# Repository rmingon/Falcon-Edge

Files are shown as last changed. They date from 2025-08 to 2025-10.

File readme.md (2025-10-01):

# FALCON-EDGE — An Open-Source Flying-Wing with an ESP32 Flight Computer

This repository contains hardware designs, documentation, and code for an aircraft project.

### New light version 400g instead of 800g

Falcon-Edge light

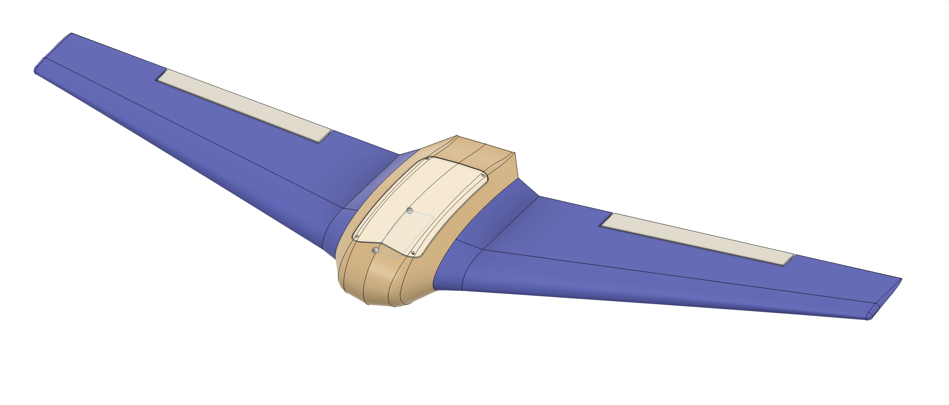
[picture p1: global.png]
Falcon-Edge render


Falcon-Edge is a compact flying-wing airframe with a custom **ESP32-based flight computer**.  
This repo contains the **KiCad hardware project** and **3D CAD** needed to print, assemble, and fly your own Falcon-Edge.

---

## Highlights

- **Airframe**

  - 3D-printable center pod with **top and bottom service hatches** for fast access.
  - Designed for clean airflow over the pod; embedded antenna keep-out zone.
  - Uses off-the-shelf wing cores/foam or your own prints.

- **Avionics (KiCad)**
  - **ESP32-WROOM** module as the main controller (Wi-Fi/BLE for ground testing & logs).
  - **IMU:** MPU-6050 6-axis.
  - **Baro:** BMP280.
  - **GNSS header** for a u-blox NEO-style GPS module.
  - **Power:** AMS1117 regulators (3V3/5V) and dedicated servo power planes/decoupling.
  - **Programming:** UART header with EN/BOOT auto-reset circuitry.
  - **RF/Telemetry:** LoRa with edge SMA/U.FL footprint for an external antenna.

> See the schematic for exact pin mapping and connector naming.

---

## 📂 Repository Layout

hardware/ # KiCad project (.kicad_pro, .kicad_pcb, .kicad_sch, etc.)
cad/ # 3D parts for the center pod, hatches, and mounting (STLs/STEP)
images/ # Renders and board views used in this README (optional)

(If you keep everything at the repo root, this README references the images there by filename.)

---

## 🛠️ Getting Started

### 1) Hardware (KiCad)

- Open with **KiCad 8.x** or newer.
- Files:
  - `hardware.kicad_pro` – project
  - `hardware.kicad_sch` – schematic
  - `hardware.kicad_pcb` – PCB layout
- Generate Gerbers/BoM as usual and order from your preferred fab.

**Board preview**
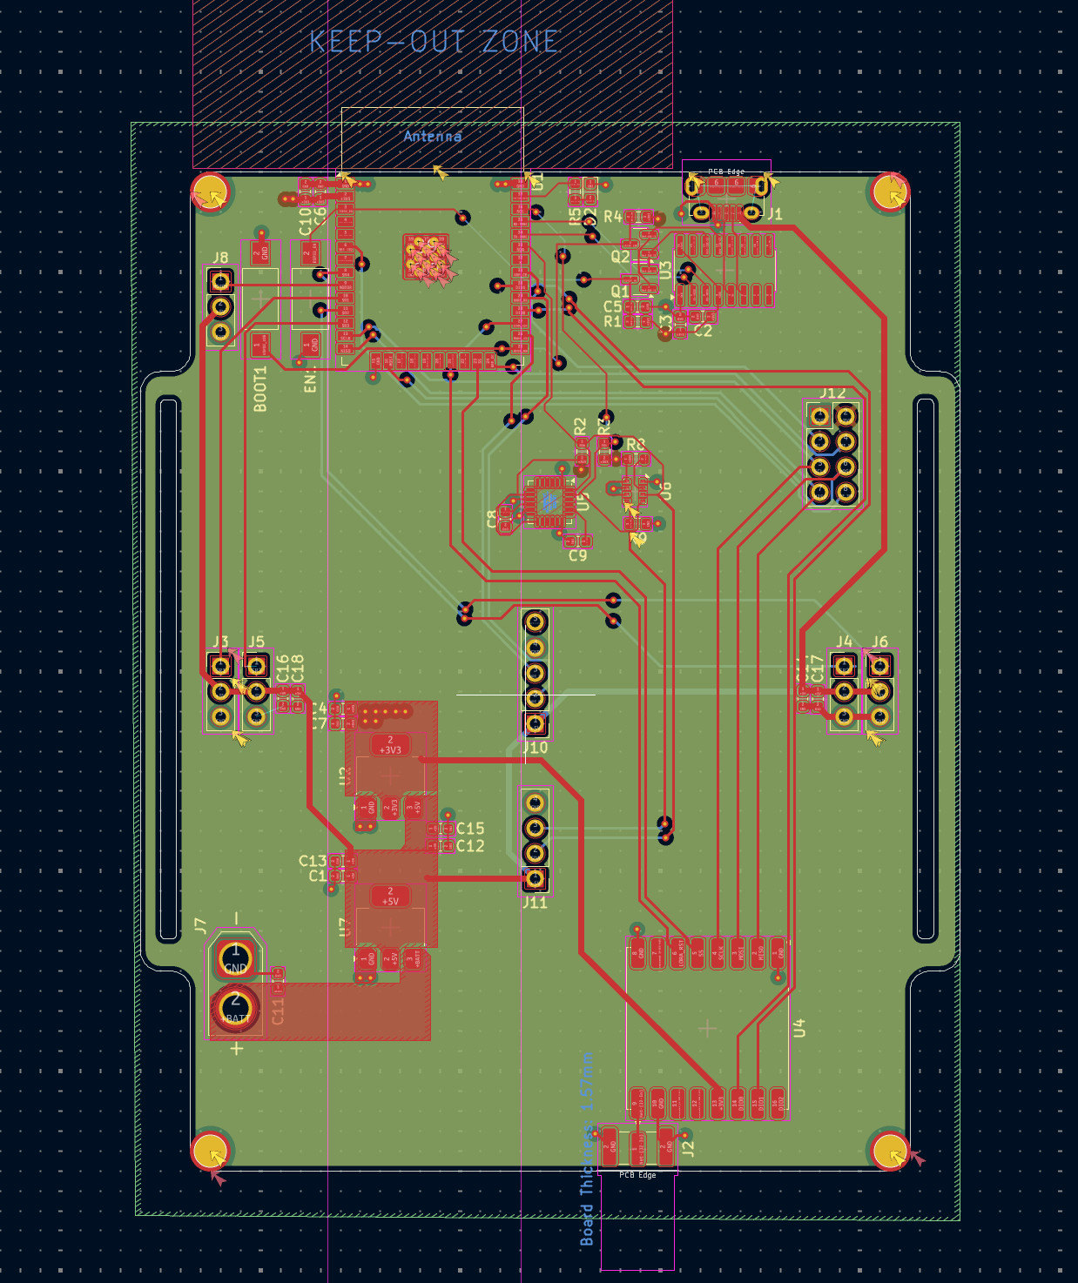
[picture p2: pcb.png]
PCB top


**Schematic overview**
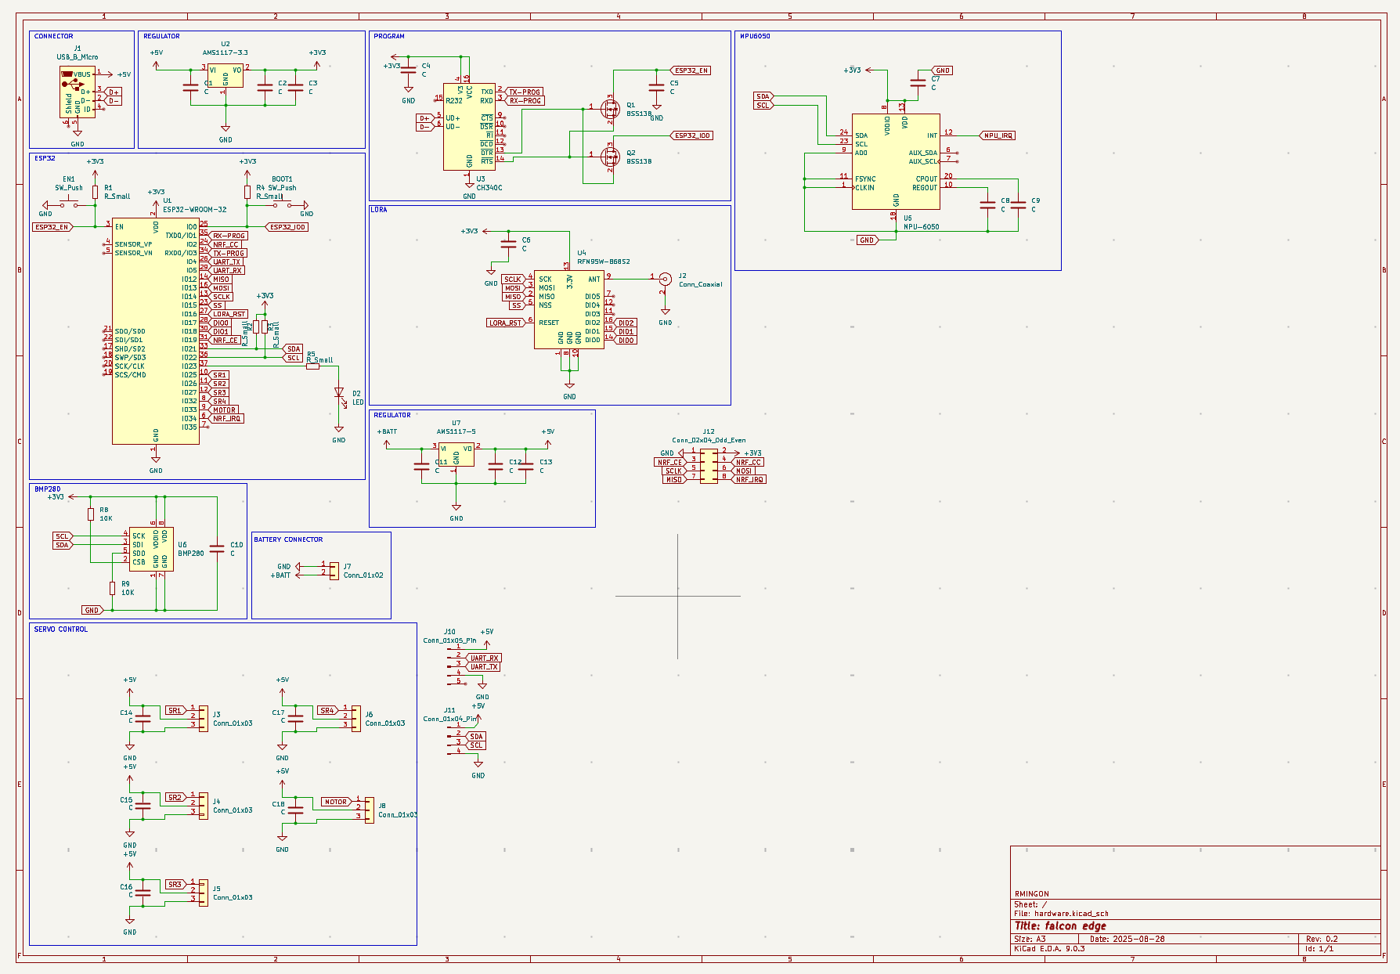
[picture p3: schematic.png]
Schematic


### 2) Print & Fit the Pod

- Recommended: **PETG** or **ABS** for the pod & hatches (heat-tolerant in the sun).
- Use heat-set **M3 inserts** for the hatch screws and board standoffs.
- Verify antenna **keep-out** in the pod before final mounting.

**Top hatch opening**
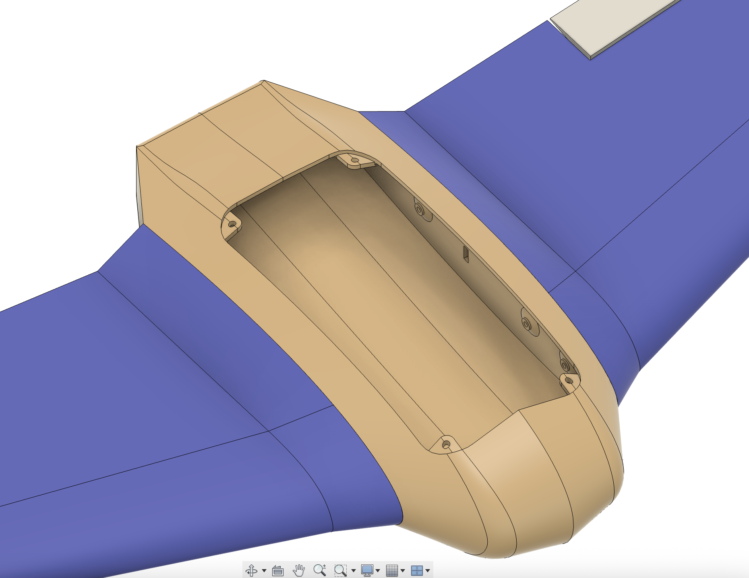
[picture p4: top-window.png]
Top hatch opening


**Bottom hatch opening**
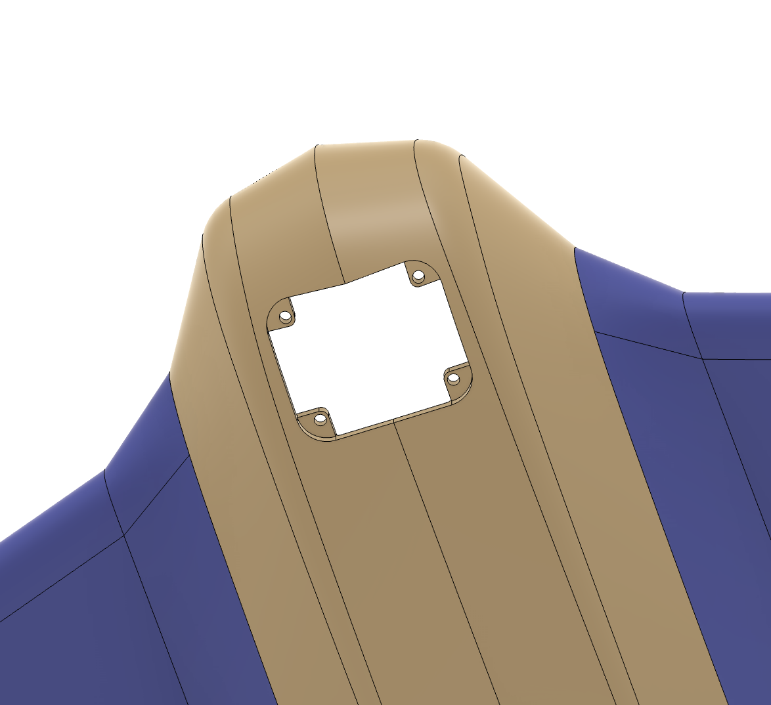
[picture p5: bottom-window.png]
Bottom hatch opening


### 3) Wiring (at a glance)

- **Battery in** → power/battery header near regulators.
- **GPS** → dedicated UART header / GPS footprint.
- **Programming** → UART (EN/BOOT accessible).
- **Telemetry/Radio** → SMA/U.FL at the board edge.

> Exact connector names/positions: see the KiCad schematic & silkscreen.

---

## 📸 Gallery

**3D view of the board**
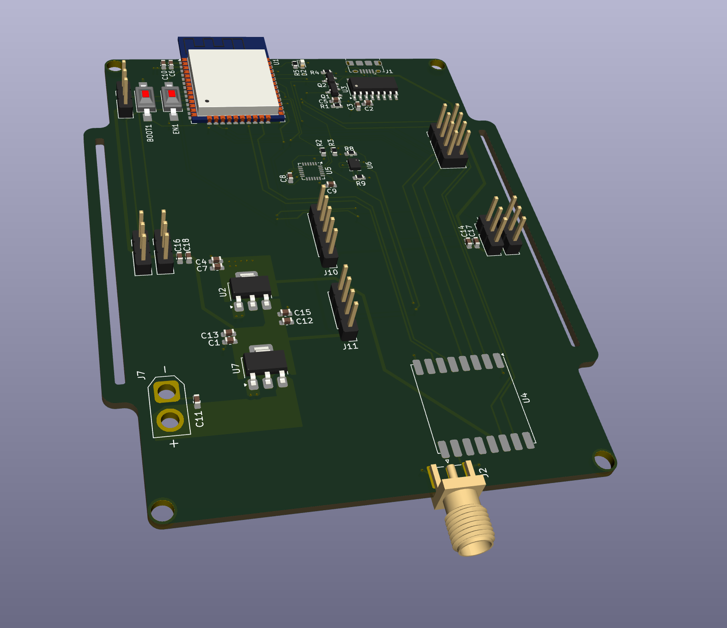
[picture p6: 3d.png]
3D board


**Airframe with pod & hatches**
Airframe render

---

## 📏 Design Notes & Decisions

- **ESP32** was chosen for its strong dev-tooling and built-in wireless (great for bench testing/logging).
- **I²C sensor stack** (MPU-6050 + BMP280) keeps routing simple and expandable.
- **PCA9685** provides plenty of PWM channels beyond the two elevons (landing gear, camera gimbal, accessories).
- **Serviceability first:** both hatches allow quick access to battery, connectors, and the main board.

---

## 🗺️ Roadmap

- Flight firmware & mixer (stabilization, RTL, waypointing).
- Airspeed/Pitot and magnetometer options.
- On-board logging (SPI flash / SD).
- CAN/Telemetry radio module footprints.
- STL release of wing cores/center pod variants.

---

## 🤝 Contributing

PRs and issues are welcome:

- Hardware changes: update the KiCad files and include board screenshots.
- CAD tweaks: include STEP/STL and a short note on print settings.
- Please attach images when reporting fit or routing problems.

---

## License Overview

- **Hardware (schematics, PCB, CAD, design files):** CERN-OHL-S-2.0 (see `LICENSE-hardware`)
- **Documentation, images, drawings, renders:** CC BY 4.0 (see `LICENSE-docs`)
- **Software / firmware / scripts:** Apache 2.0 (see `LICENSE-code`)

## Attribution Requirement

If you use, modify, or redistribute any part of this project, you **must** give credit as follows:

> Based on FalconEgde by Rmingon (https://github.com/rmingon/Falcon-Edge) — Licensed under the corresponding license.

See `NOTICE` for full details.

---

## 🙏 Credits

Designed and built by **RMINGON**.

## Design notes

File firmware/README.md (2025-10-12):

# Falcon-Edge Flight Controller Firmware

FreeRTOS-based ESP32 firmware for a drone flight controller with altitude and attitude control.

## Hardware Configuration

### ESP32 Pinout

#### I2C Bus (Sensors)
- **SDA**: GPIO 21
- **SCL**: GPIO 22

Connected sensors:
- **BMP280** - Barometric pressure/altitude sensor (I2C address: 0x76)
- **HMC5883L** - 3-axis magnetometer (I2C address: 0x1E)
- **MPU6050** - 6-axis IMU (accelerometer + gyroscope) (I2C address: 0x68)

#### SPI Bus (LoRa)
- **MISO**: GPIO 12
- **MOSI**: GPIO 13
- **SCK**: GPIO 14
- **SS/CS**: GPIO 15
- **RST**: GPIO 16
- **DIO0**: GPIO 17 (interrupt line)
- **DIO1**: GPIO 18 (interrupt line)

Connected device:
- **RFM95** - LoRa transceiver module (915 MHz)

#### UART (GPS)
- **TX**: GPIO 4
- **RX**: GPIO 5

Connected device:
- **ATGM336H** - GPS module (9600 baud, NMEA protocol)

## Features

### Sensors
- **MPU6050**: 6-axis IMU (3-axis accelerometer + 3-axis gyroscope)
- **HMC5883L**: 3-axis magnetometer for heading measurement
- **BMP280**: Barometric pressure sensor for altitude measurement
- **ATGM336H**: GPS module for position tracking

### Control System
- **PID Controllers**:
  - Altitude control (using BMP280 barometer)
  - Roll control (using IMU data)
  - Pitch control (using IMU data)
  - Yaw control (using magnetometer + gyro)

- **Sensor Fusion**:
  - Complementary filter for roll/pitch (combines accelerometer and gyroscope)
  - Magnetometer-based yaw with tilt compensation
  - Gyroscope integration with magnetometer correction

### Communication
- **LoRa telemetry**: Sends real-time flight data (attitude, altitude, GPS position)
- **Command reception**: Receives commands via LoRa (arm, disarm, set setpoints)

### FreeRTOS Tasks
1. **Sensor Task** (100 Hz) - Reads all sensors
2. **Control Task** (100 Hz) - Updates attitude estimation and PID controllers
3. **GPS Task** (10 Hz) - Processes GPS data
4. **LoRa Task** (1 Hz) - Sends telemetry
5. **Command Task** - Receives and processes LoRa commands

## Building and Flashing

### Prerequisites
- ESP-IDF v4.4 or later
- PlatformIO (optional)

### Using PlatformIO
```bash
cd firmware
pio run -t upload
pio device monitor
```

### Using ESP-IDF
```bash
cd firmware
idf.py build
idf.py -p /dev/ttyUSB0 flash monitor
```

## Configuration

All configuration parameters are in [include/config.h](include/config.h):

- **Sensor pins and I2C settings**
- **LoRa frequency and SPI pins**
- **GPS UART settings**
- **PID tuning parameters** (Kp, Ki, Kd)
- **Task priorities and stack sizes**
- **Sensor sample rates**

### PID Tuning

Default PID parameters are set in [config.h](include/config.h). You can tune them for your specific setup:

```c
// Altitude PID
#define ALT_PID_KP    2.0f
#define ALT_PID_KI    0.5f
#define ALT_PID_KD    1.0f

// Roll PID
#define ROLL_PID_KP   1.5f
#define ROLL_PID_KI   0.3f
#define ROLL_PID_KD   0.8f

// Pitch PID
#define PITCH_PID_KP  1.5f
#define PITCH_PID_KI  0.3f
#define PITCH_PID_KD  0.8f

// Yaw PID
#define YAW_PID_KP    2.0f
#define YAW_PID_KI    0.1f
#define YAW_PID_KD    1.2f
```

## LoRa Commands

The system accepts the following commands via LoRa:

### Arm Command
Send single byte: `'A'` (0x41)
- Arms the flight controller and enables control outputs

### Disarm Command
Send single byte: `'D'` (0x44)
- Disarms the flight controller and zeros all outputs

### Set Setpoints Command
Send 17 bytes: `'S'` + 4 floats (altitude, roll, pitch, yaw)
- Format: `['S'][altitude][roll][pitch][yaw]`
- Each float is 4 bytes (little-endian)
- Example: Set altitude to 10m, level attitude (0° roll/pitch), 90° heading

## Telemetry Data

Telemetry is sent via LoRa every second containing:
- Roll (degrees)
- Pitch (degrees)
- Yaw (degrees)
- Altitude (meters)
- GPS latitude (degrees)
- GPS longitude (degrees)
- Number of GPS satellites
- Armed status (1 byte boolean)

Total packet size: ~30 bytes

## System Architecture

```
┌─────────────────────────────────────────────────────┐
│                    ESP32 Main                        │
│  ┌────────────────────────────────────────────────┐ │
│  │         FreeRTOS Task Scheduler                │ │
│  └────────────────────────────────────────────────┘ │
│                                                       │
│  ┌──────────┐  ┌───────────┐  ┌─────────┐          │
│  │  Sensor  │  │  Control  │  │  LoRa   │          │
│  │   Task   │→│   Task    │→│  Task   │          │
│  │ (100 Hz) │  │ (100 Hz)  │  │ (1 Hz)  │          │
│  └──────────┘  └───────────┘  └─────────┘          │
│       ↓              ↓                                │
│  ┌──────────────────────────────────────────────┐   │
│  │         Flight Controller Module             │   │
│  │  • Sensor Fusion (Complementary Filter)     │   │
│  │  • 4x PID Controllers                       │   │
│  │  • Attitude Estimation                      │   │
│  └──────────────────────────────────────────────┘   │
│       ↓                                               │
│  ┌──────────┬──────────┬──────────┐                 │
│  │  MPU6050 │ HMC5883L │  BMP280  │  (I2C)         │
│  └──────────┴──────────┴──────────┘                 │
│  ┌──────────┐  ┌─────────────┐                      │
│  │ ATGM336  │  │   RFM95     │                      │
│  │   GPS    │  │   LoRa      │                      │
│  └──────────┘  └─────────────┘                      │
│    (UART)          (SPI)                             │
└─────────────────────────────────────────────────────┘
```

## Safety Features

- **Calibration check**: System must be calibrated before arming
- **Armed state**: Control outputs are zero when disarmed
- **Mutex protection**: Thread-safe access to shared data
- **PID anti-windup**: Prevents integral term from growing unbounded
- **Output limiting**: All PID outputs are clamped to safe ranges

## Serial Monitor Output

When running, you'll see output like:
```
I (1234) Main: Attitude: R=2.3° P=-1.5° Y=45.2° | Alt=123.45m | GPS: 37.774929,-122.419418 (8 sats)
I (1234) Main: Control outputs: Alt=15.2 Roll=-3.4 Pitch=2.1 Yaw=0.8
```

## License

See the LICENSE file in the repository root.

## Troubleshooting

### Sensor initialization fails
- Check I2C connections and pull-up resistors
- Verify sensor I2C addresses (some modules use alternate addresses)
- Check power supply (3.3V for all sensors)

### GPS not getting fix
- Ensure antenna has clear view of sky
- GPS may take several minutes for first fix
- Check UART baud rate (9600 for ATGM336)

### LoRa not working
- Verify antenna is connected
- Check SPI connections
- Ensure frequency matches your region (915 MHz US, 868 MHz EU, 433 MHz Asia)
- Check DIO0/DIO1 interrupt pins are connected

### Attitude estimation drifts
- Recalibrate IMU (keep device stationary during calibration)
- Adjust complementary filter alpha values
- Check for magnetic interference affecting magnetometer

## Future Improvements

- [ ] Kalman filter for better sensor fusion
- [ ] Motor/ESC control outputs
- [ ] Battery voltage monitoring
- [ ] Failsafe modes
- [ ] SD card logging
- [ ] Web interface for configuration
- [ ] OTA firmware updates

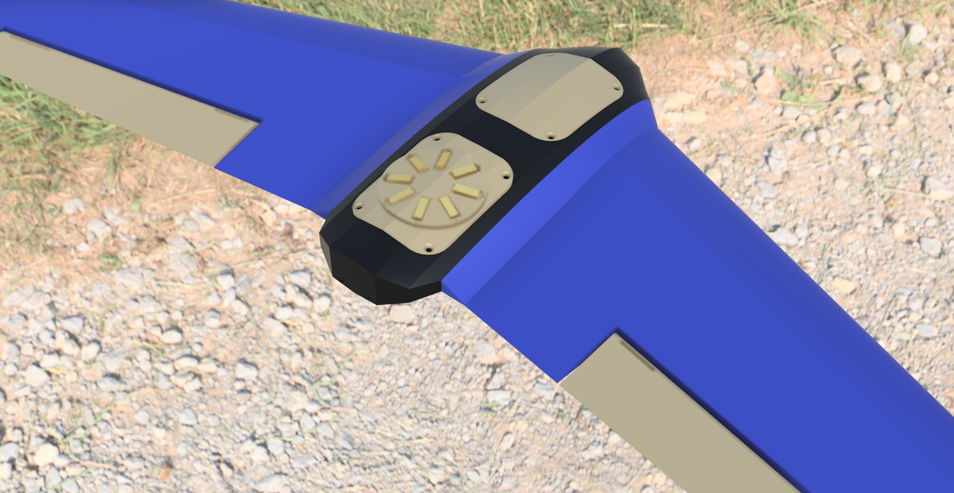
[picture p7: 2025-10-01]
plane_gps_module.png

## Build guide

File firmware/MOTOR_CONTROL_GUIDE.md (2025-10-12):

# Motor & Servo Control Guide

## Hardware Configuration

Your fixed-wing drone now has full motor and servo control!

### Pin Assignments

| Component | GPIO | Signal Type |
|---|---|---|
| **Left Wing Servo** | GPIO 26 | PWM (50Hz) |
| **Right Wing Servo** | GPIO 25 | PWM (50Hz) |
| **ESC (Motor)** | GPIO 33 | PWM (50Hz) |

### PWM Signal Specs

- **Frequency**: 50 Hz (20ms period)
- **Servo Range**: 1000-2000μs (±45° from center)
- **Servo Center**: 1500μs (neutral position)
- **ESC Range**: 1000-2000μs (0-100% throttle)
- **ESC Idle**: 1100μs (motor spinning, low throttle)

## Control Mixing (Fixed-Wing)

Your firmware implements **fixed-wing control mixing** that converts PID outputs to servo/motor commands:

### Roll Control (Ailerons)
```
Left Servo Angle  = +Roll_Output * 0.3
Right Servo Angle = -Roll_Output * 0.3
```
- Roll right (+): Left servo up, right servo down
- Roll left (-): Left servo down, right servo up

### Pitch Control (Elevators)
```
Both Servos = +Pitch_Output * 0.3
```
- Pitch up (+): Both servos up
- Pitch down (-): Both servos down

### Yaw Control (Rudder via Differential)
```
Left Servo  += +Yaw_Output * 0.1
Right Servo += -Yaw_Output * 0.1
```
- Small differential aileron for yaw stability

### Altitude Control (Throttle)
```
Throttle = 50% + Altitude_Output * 0.5
```
- Base throttle: 50%
- Adjusts ±50% based on altitude PID

## Safety Features

### Arming Sequence
1. System checks calibration
2. **ESC arming**: 2-second low throttle signal
3. PIDs reset to zero
4. Flight controller armed
5. Control outputs active

### Disarming
- All servos return to center (0°)
- Throttle set to 0%
- Control loop stops updating outputs

### Fail-Safe
When disarmed:
- Servos: Centered
- Motor: Zero throttle
- No PID updates

## Testing

### Bench Testing (NO PROPELLER!)

**Test servos:**
```c
// In your code or via serial commands
motor_set_servo_left(&motor, 20.0f);   // 20° up
motor_set_servo_right(&motor, -10.0f); // 10° down
```

**Test ESC (REMOVE PROPELLER FIRST!):**
```c
motor_set_throttle(&motor, 10.0f);  // 10% throttle - should spin slowly
```

### Serial Monitor Output

When arming:
```
I (12345) MotorControl: Motor control initialized - Left:26 Right:25 ESC:33
I (23456) FlightController: Arming flight controller
I (23457) MotorControl: Arming ESC sequence...
I (25457) MotorControl: ESC armed
I (25458) FlightController: Flight controller armed - ready to fly
```

## Tuning

### Servo Travel Adjustment

In [motor_control.c](src/motor_control.c:17):
```c
// Increase for more servo throw
float pulse = SERVO_CENTER_PULSE_US + (angle / 45.0f) * 500.0f;
                                                    // ^^^^ change this
```

### Control Surface Gains

In [flight_controller.c](src/flight_controller.c:216-226):
```c
// Aileron gain (roll)
left_servo += fc->roll_output * 0.3f;   // Increase for more roll authority

// Elevator gain (pitch)
left_servo += fc->pitch_output * 0.3f;  // Increase for more pitch authority

// Rudder gain (yaw)
left_servo += fc->yaw_output * 0.1f;    // Increase for more yaw authority
```

### Throttle Control

```c
float throttle = 50.0f;  // Base throttle (cruise speed)
throttle += fc->altitude_output * 0.5f;  // Altitude response gain
```

## Servo Reversing

If a servo moves in the wrong direction, reverse it in the mixing:

### Reverse Left Servo
```c
left_servo -= fc->roll_output * 0.3f;  // Changed + to -
```

### Reverse Right Servo
```c
right_servo += fc->roll_output * 0.3f;  // Changed - to +
```

## ESC Calibration

Some ESCs need calibration. If your ESC doesn't work:

1. **Power off** drone
2. Set throttle to **max** in code temporarily:
   ```c
   motor_set_throttle(&motor, 100.0f);
   ```
3. **Power on** drone with battery
4. Wait for ESC beeps (confirms max throttle)
5. Set throttle to **min**:
   ```c
   motor_set_throttle(&motor, 0.0f);
   ```
6. Wait for ESC beeps (confirms min throttle)
7. **Remove** temporary code, upload normal firmware

## Common Issues

### Servos jittering
- Check power supply (servos draw current)
- Add capacitor (100-470μF) to servo power rail
- Ensure common ground between ESP32 and servo power

### ESC not responding
- Check ESC is receiving 5V/3.3V signal (not vice versa)
- Verify PWM signal with oscilloscope
- Try ESC calibration procedure above
- Some ESCs need 3.3V → 5V level shifter

### Servos moving wrong direction
- See "Servo Reversing" section above
- Or swap servo connections physically

### ESC beeping continuously
- Usually means low voltage or no signal
- Check battery voltage
- Verify PWM signal present on GPIO 33

## API Reference

### Set Individual Outputs
```c
motor_set_servo_left(&motor, angle);   // -45 to +45 degrees
motor_set_servo_right(&motor, angle);  // -45 to +45 degrees
motor_set_throttle(&motor, percent);   // 0 to 100%
```

### Set All Outputs
```c
motor_set_all(&motor, left_angle, right_angle, throttle);
```

### Safety Functions
```c
motor_arm_esc(&motor);    // Run ESC arming sequence
motor_disarm(&motor);     // Stop all outputs
```

## Wiring Diagram

```
ESP32                     Servos/ESC
┌─────────┐
│ GPIO 26 ├──────────┬───► Left Wing Servo (Signal)
│         │          │
│ GPIO 25 ├──────────┼───► Right Wing Servo (Signal)
│         │          │
│ GPIO 33 ├──────────┼───► ESC (Signal)
│         │          │
│    GND  ├──────────┴───► Common Ground
└─────────┘

Power:
- Servos: 5V from BEC/ESC
- ESC: Main battery (LiPo)
- ESP32: 5V from USB or BEC (via voltage regulator)

⚠️ IMPORTANT: Common ground required!
```

## Next Steps

1. **Bench test** servos without propeller
2. **Calibrate ESC** if needed
3. **Tune mixing gains** for your aircraft
4. **Test on ground** with prop, full arm sequence
5. **Flight test** in stable conditions

Happy flying! 🚀

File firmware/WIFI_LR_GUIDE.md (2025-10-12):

# WiFi Long Range Guide

## Overview

Your ESP32 firmware now supports **WiFi Long Range (LR) mode** alongside LoRa for redundant telemetry and configuration.

## Features Added

### 1. **WiFi Long Range Mode**
- Range: Up to **1 km** line-of-sight
- Frequency: 5 Hz telemetry updates
- Dual-band support with LoRa as backup

### 2. **UDP Telemetry**
- Sends flight data to ground station at `192.168.4.1:5000`
- Same packet format as LoRa telemetry
- Lower latency than LoRa

### 3. **Remote WiFi Configuration**
- Configure WiFi via LoRa commands
- No need to reflash firmware to change networks

## Configuration

### In [config.h](include/config.h)

```c
#define WIFI_ENABLED              true        // Enable/disable WiFi
#define WIFI_DEFAULT_SSID         "DroneGCS"  // Your WiFi network
#define WIFI_DEFAULT_PASSWORD     "drone123"  // Your WiFi password
```

### Ground Station IP

Change in [wifi_lr.c](src/wifi_lr.c:10):
```c
#define GROUND_STATION_IP       "192.168.4.1"  // Your ground station IP
```

## Usage

### Auto-Connect on Startup

If you set `WIFI_DEFAULT_SSID` and `WIFI_DEFAULT_PASSWORD` in config.h, the drone will automatically connect on boot.

### Connect via LoRa Command

Send command `'W'` via LoRa with this format:
```
Byte 0: 'W' (0x57)
Byte 1: SSID length (N)
Bytes 2 to N+1: SSID string
Bytes N+2 to end: Password string
```

**Example Python code to send WiFi config:**
```python
import struct

ssid = "MyDrone"
password = "password123"

packet = bytearray()
packet.append(ord('W'))           # Command
packet.append(len(ssid))          # SSID length
packet.extend(ssid.encode())      # SSID
packet.extend(password.encode())  # Password

# Send packet via your LoRa module
lora.send(packet)
```

## Ground Station Setup

### Simple UDP Receiver (Python)

```python
import socket
import struct

UDP_IP = "0.0.0.0"
UDP_PORT = 5000

sock = socket.socket(socket.AF_INET, socket.SOCK_DGRAM)
sock.bind((UDP_IP, UDP_PORT))

print(f"Listening for telemetry on {UDP_IP}:{UDP_PORT}")

while True:
    data, addr = sock.recvfrom(1024)

    if len(data) >= 29:
        # Unpack telemetry
        roll, pitch, yaw, alt, lat, lon, sats, armed = struct.unpack('<ffffffBB', data[:29])

        print(f"Drone at {addr[0]}:")
        print(f"  Attitude: R={roll:.1f}° P={pitch:.1f}° Y={yaw:.1f}°")
        print(f"  Altitude: {alt:.2f}m")
        print(f"  GPS: {lat:.6f}, {lon:.6f} ({sats} sats)")
        print(f"  Armed: {bool(armed)}")
        print()
```

## Serial Monitor Output

When WiFi is working, you'll see:
```
I (12345) WiFi_LR: WiFi Long Range mode initialized
I (12456) WiFi_LR: Connecting to WiFi: DroneGCS
I (15234) WiFi_LR: Got IP: 192.168.4.2
I (15345) Main: WiFi task started
I (20000) Main: WiFi connected, RSSI: -45 dBm
```

## Troubleshooting

### WiFi won't connect
1. Check SSID and password in config.h
2. Ensure AP supports 802.11n or 802.11b/g
3. Check serial monitor for error messages
4. Verify ESP32 is in range (~1km max)

### No telemetry received
1. Check ground station IP in wifi_lr.c
2. Verify UDP port 5000 is not blocked by firewall
3. Ensure ground station is on same network
4. Check RSSI in serial monitor (should be > -80 dBm)

### High packet loss
- Move closer to AP (check RSSI)
- Reduce obstacles between drone and AP
- Lower `WIFI_TX_RATE_HZ` in config.h to reduce bandwidth

## Disable WiFi

To disable WiFi completely:

In [config.h](include/config.h):
```c
#define WIFI_ENABLED    false
```

This will remove WiFi task and save memory.

## Comparison: WiFi LR vs LoRa

| Feature | WiFi LR | LoRa |
|---|---|---|
| **Range** | ~1 km | 2-15 km |
| **Data Rate** | 5 Hz | 1 Hz |
| **Latency** | ~10 ms | ~100 ms |
| **Power** | Higher | Lower |
| **Best For** | Near-field ops | Long-range |

**Recommendation**: Use both! WiFi for low-latency control near base, LoRa for long-range missions.

## Advanced: Bidirectional Commands via WiFi

You can easily extend the WiFi module to receive commands (not just send telemetry):

1. Add TCP server in wifi_lr.c
2. Parse incoming command packets
3. Call flight controller functions

This would allow real-time parameter tuning over WiFi!

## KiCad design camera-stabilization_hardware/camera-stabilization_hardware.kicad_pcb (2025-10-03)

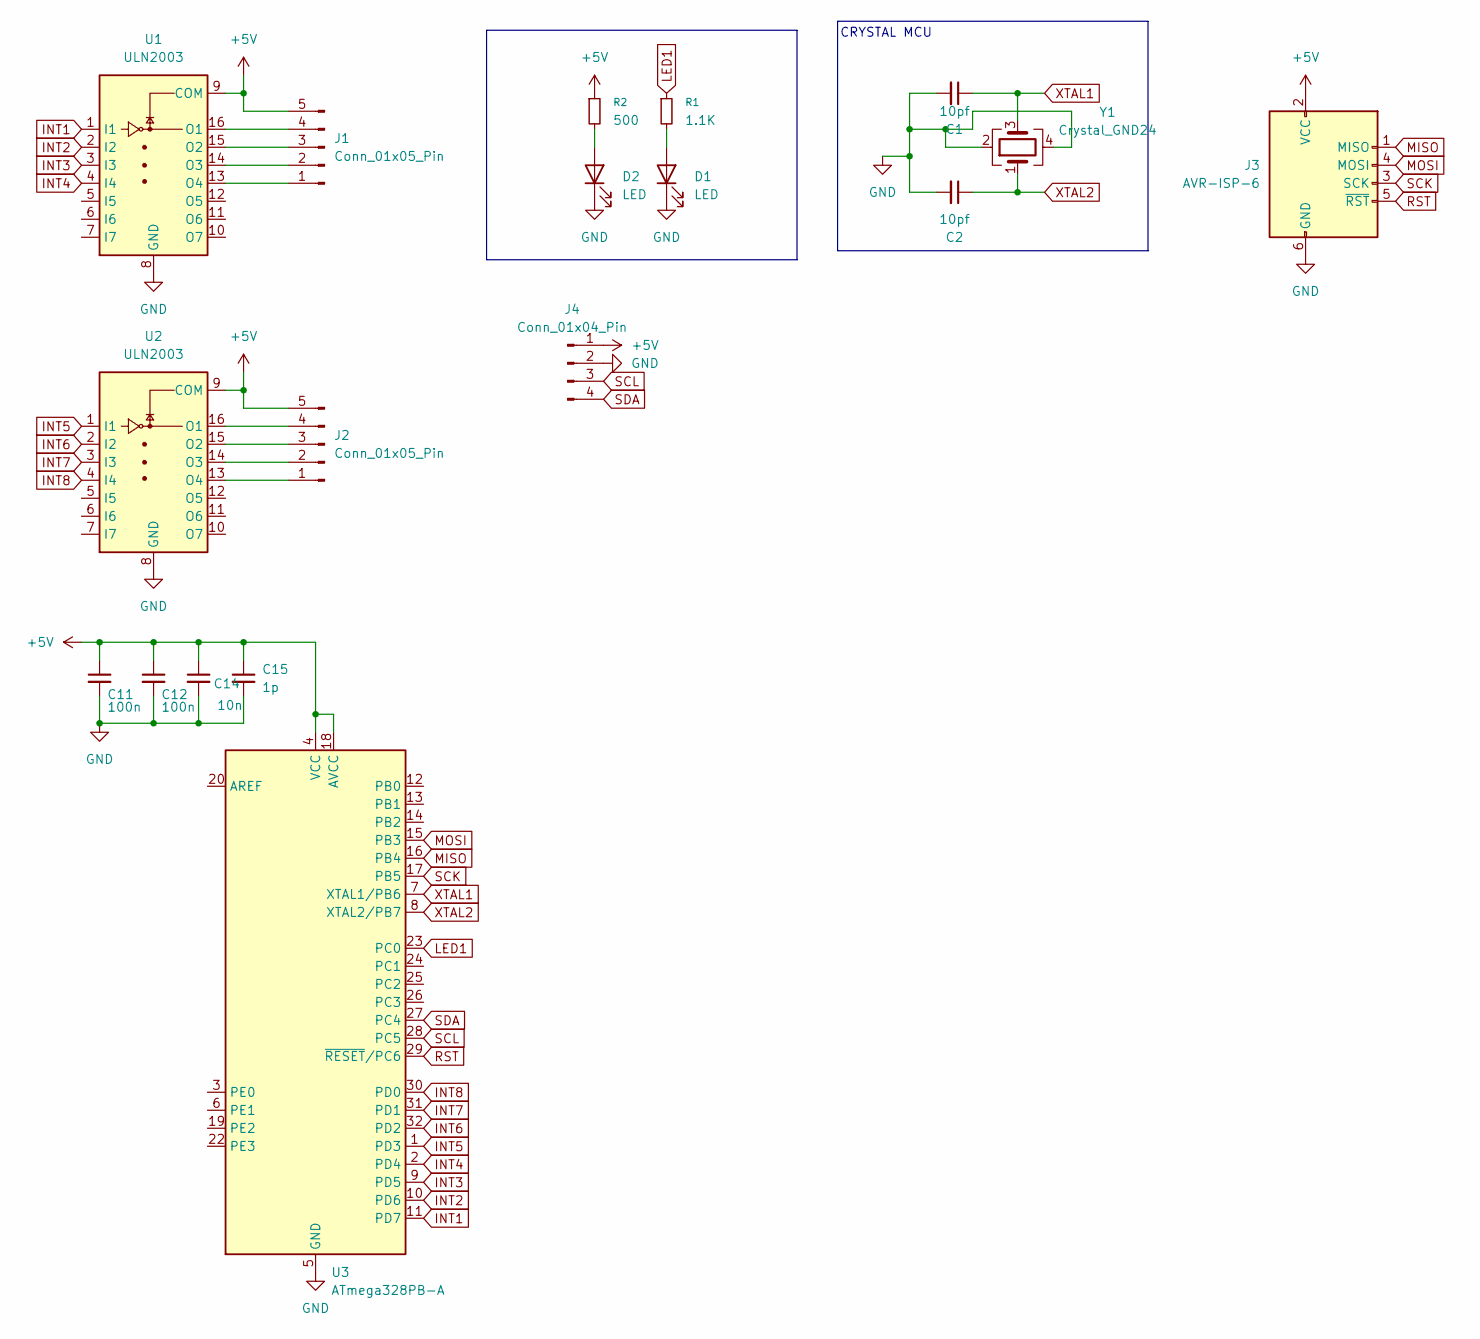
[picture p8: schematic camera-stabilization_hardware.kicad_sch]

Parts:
C1, C2: 10pf; C_0603_1608Metric; LCSC C106245
C11, C12: 100n; C_0603_1608Metric
C14: 10n; C_0603_1608Metric
C15: 1p; C_0603_1608Metric
D1, D2: LED; LED_0603_1608Metric
J1, J2: Conn_01x05_Pin; JST_XH_B5B-XH-A_1x05_P2.50mm_Vertical
J3: AVR-ISP-6; PinHeader_2x03_P2.54mm_Vertical
J4: Conn_01x04_Pin; JST_SH_BM04B-SRSS-TB_1x04-1MP_P1.00mm_Vertical
R1: 1.1K; R_0603_1608Metric
R2: 500; R_0603_1608Metric
U1, U2: ULN2003; SOIC-16_3.9x9.9mm_P1.27mm
U3: ATmega328PB-A; TQFP-32_7x7mm_P0.8mm
Y1: Crystal_GND24; Crystal_SMD_3225-4Pin_3.2x2.5mm

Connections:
+5V: C11.1, C12.1, C14.1, C15.1, J1.5, J2.5, J3.2 (VCC), J4.1, R2.1, U1.9 (COM), U2.9 (COM), U3.4 (VCC), U3.18 (AVCC)
GND: C1.2, C2.2, C11.2, C12.2, C14.2, C15.2, D1.1 (K), D2.1 (K), J3.6 (GND), J4.2, U1.8 (GND), U2.8 (GND), U3.5 (GND), U3.21 (GND), Y1.2, Y1.4
INT1: U1.1 (I1), U3.11 (PD7)
INT2: U1.2 (I2), U3.10 (PD6)
INT3: U1.3 (I3), U3.9 (PD5)
INT4: U1.4 (I4), U3.2 (PD4)
INT5: U2.1 (I1), U3.1 (PD3)
INT6: U2.2 (I2), U3.32 (PD2)
INT7: U2.3 (I3), U3.31 (PD1)
INT8: U2.4 (I4), U3.30 (PD0)
LED1: R1.1, U3.23 (PC0)
MISO: J3.1 (MISO), U3.16 (PB4)
MOSI: J3.4 (MOSI), U3.15 (PB3)
unnamed: D1.2 (A), R1.2
unnamed: D2.2 (A), R2.2
unnamed: J1.1, U1.13 (O4)
unnamed: J1.2, U1.14 (O3)
unnamed: J1.3, U1.15 (O2)
unnamed: J1.4, U1.16 (O1)
unnamed: J2.1, U2.13 (O4)
unnamed: J2.2, U2.14 (O3)
unnamed: J2.3, U2.15 (O2)
unnamed: J2.4, U2.16 (O1)
RST: J3.5 (~RST), U3.29 (~RESET/PC6)
SCK: J3.3 (SCK), U3.17 (PB5)
SCL: J4.3, U3.28 (PC5)
SDA: J4.4, U3.27 (PC4)
XTAL1: C1.1, U3.7 (XTAL1/PB6), Y1.3
XTAL2: C2.1, U3.8 (XTAL2/PB7), Y1.1

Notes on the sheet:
CRYSTAL MCU

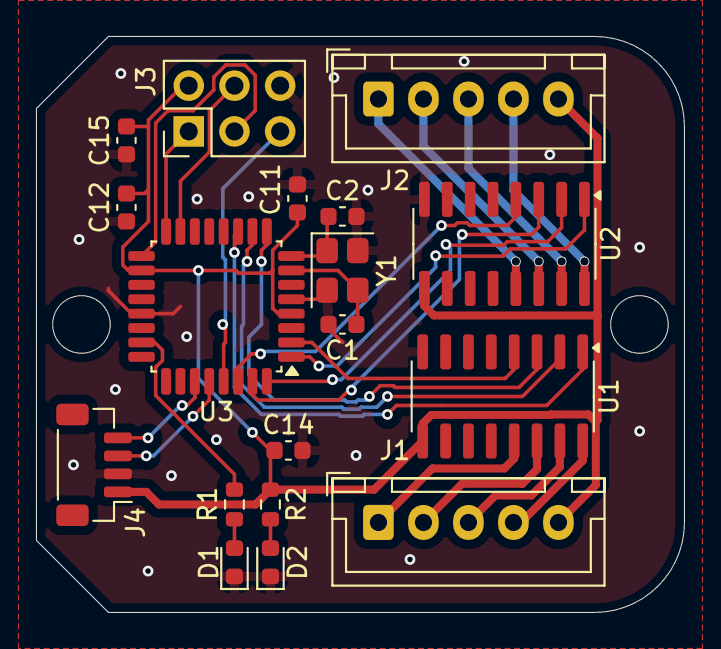
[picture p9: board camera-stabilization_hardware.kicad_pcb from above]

Board: 2 copper layers, 36.0 x 32.0 mm, 18 parts (0 on the bottom side), 29 nets.

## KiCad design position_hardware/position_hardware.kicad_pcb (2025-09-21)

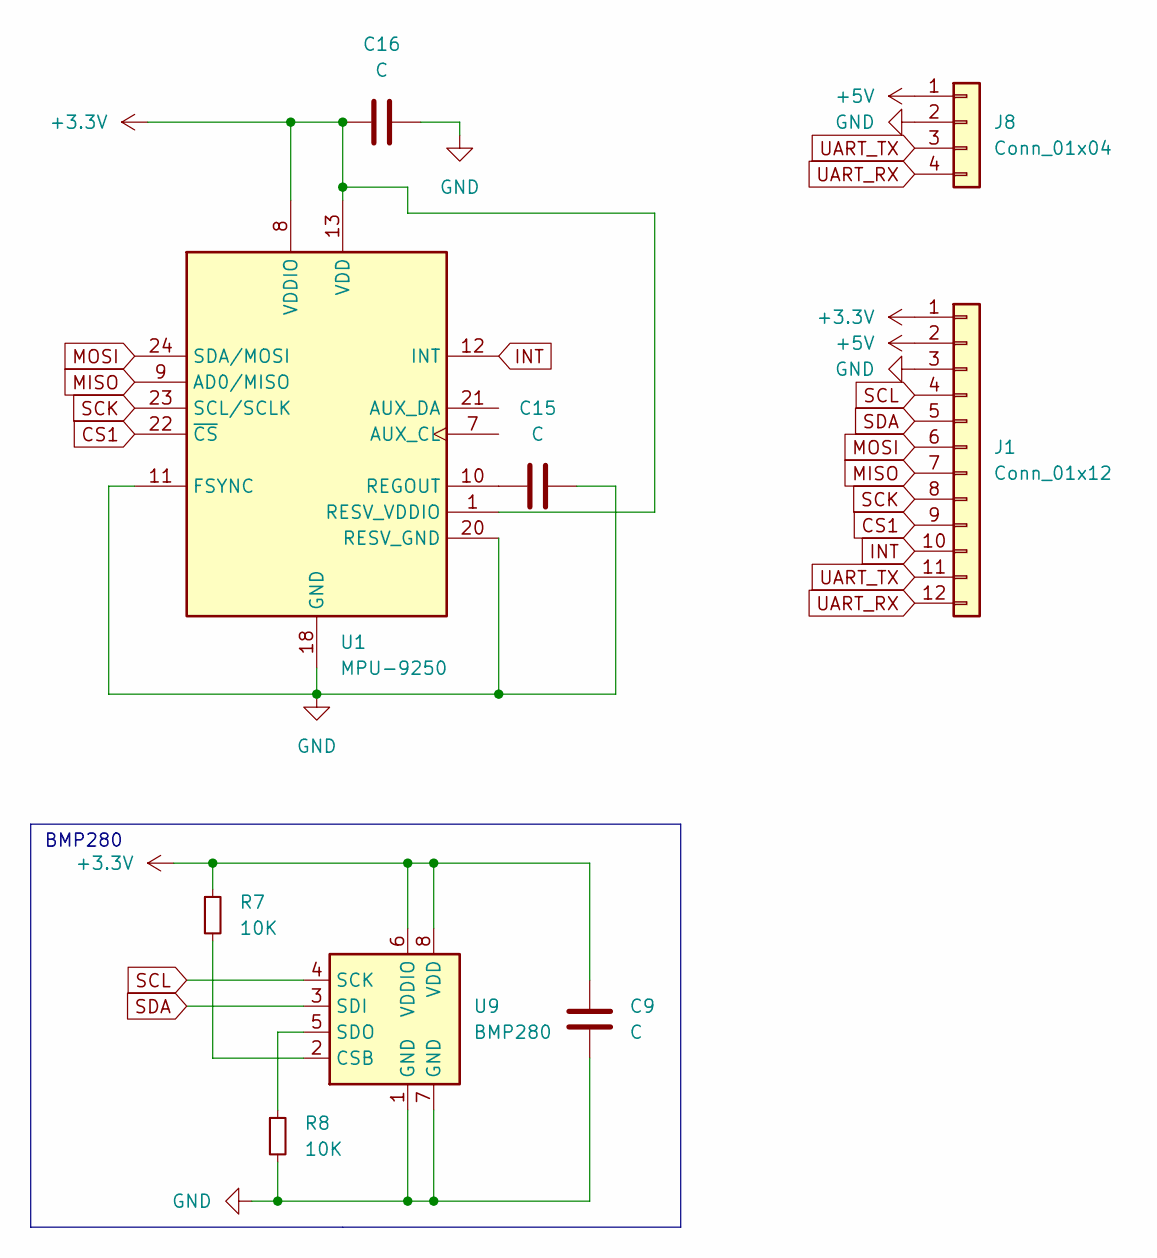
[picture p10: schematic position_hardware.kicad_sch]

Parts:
C9, C15, C16: C; C_0603_1608Metric
J1: Conn_01x12
J8: Conn_01x04; PinHeader_1x04_P2.54mm_Vertical
R7, R8: 10K; R_0603_1608Metric
U1: MPU-9250; InvenSense_QFN-24_3x3mm_P0.4mm
U9: BMP280; Bosch_LGA-8_2x2.5mm_P0.65mm_ClockwisePinNumbering

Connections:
+3.3V: C9.1, C16.1, J1.1, R7.1, U1.1 (RESV_VDDIO), U1.8 (VDDIO), U1.13 (VDD), U9.6 (VDDIO), U9.8 (VDD)
+5V: J1.2, J8.1
CS1: J1.9, U1.22 (~CS)
GND: C9.2, C15.2, C16.2, J1.3, J8.2, R8.2, U1.11 (FSYNC), U1.18 (GND), U1.20 (RESV_GND), U9.1 (GND), U9.7 (GND)
INT: J1.10, U1.12 (INT)
MISO: J1.7, U1.9 (AD0/MISO)
MOSI: J1.6, U1.24 (SDA/MOSI)
unnamed: C15.1, U1.10 (REGOUT)
unnamed: R7.2, U9.2 (CSB)
unnamed: R8.1, U9.5 (SDO)
SCK: J1.8, U1.23 (SCL/SCLK)
SCL: J1.4, U9.4 (SCK)
SDA: J1.5, U9.3 (SDI)
UART_RX: J1.12, J8.4
UART_TX: J1.11, J8.3

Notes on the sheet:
BMP280

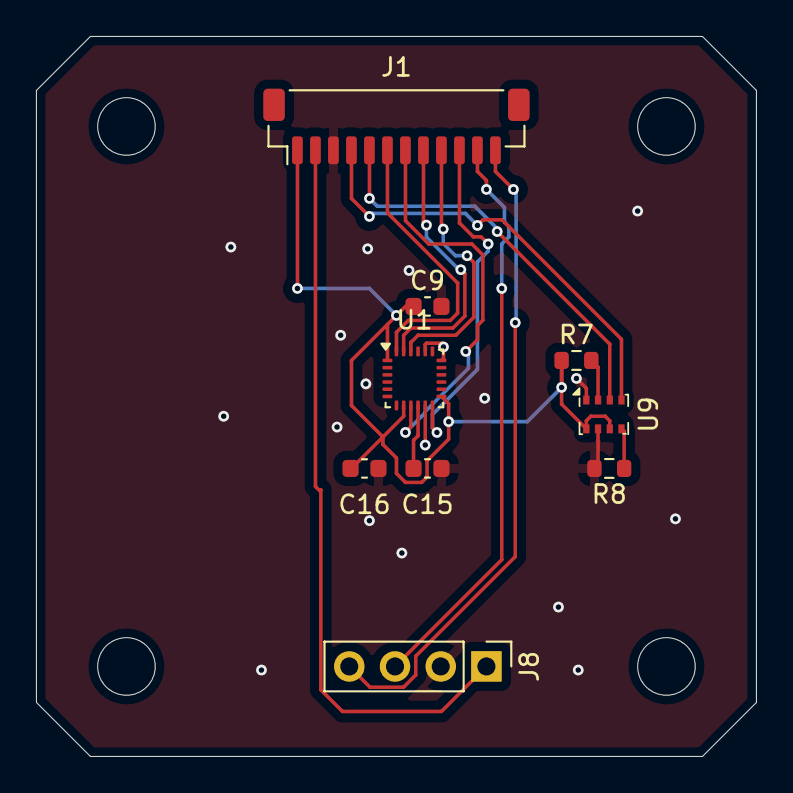
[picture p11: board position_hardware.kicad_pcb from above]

Board: 2 copper layers, 40.0 x 40.0 mm, 9 parts (0 on the bottom side), 15 nets.

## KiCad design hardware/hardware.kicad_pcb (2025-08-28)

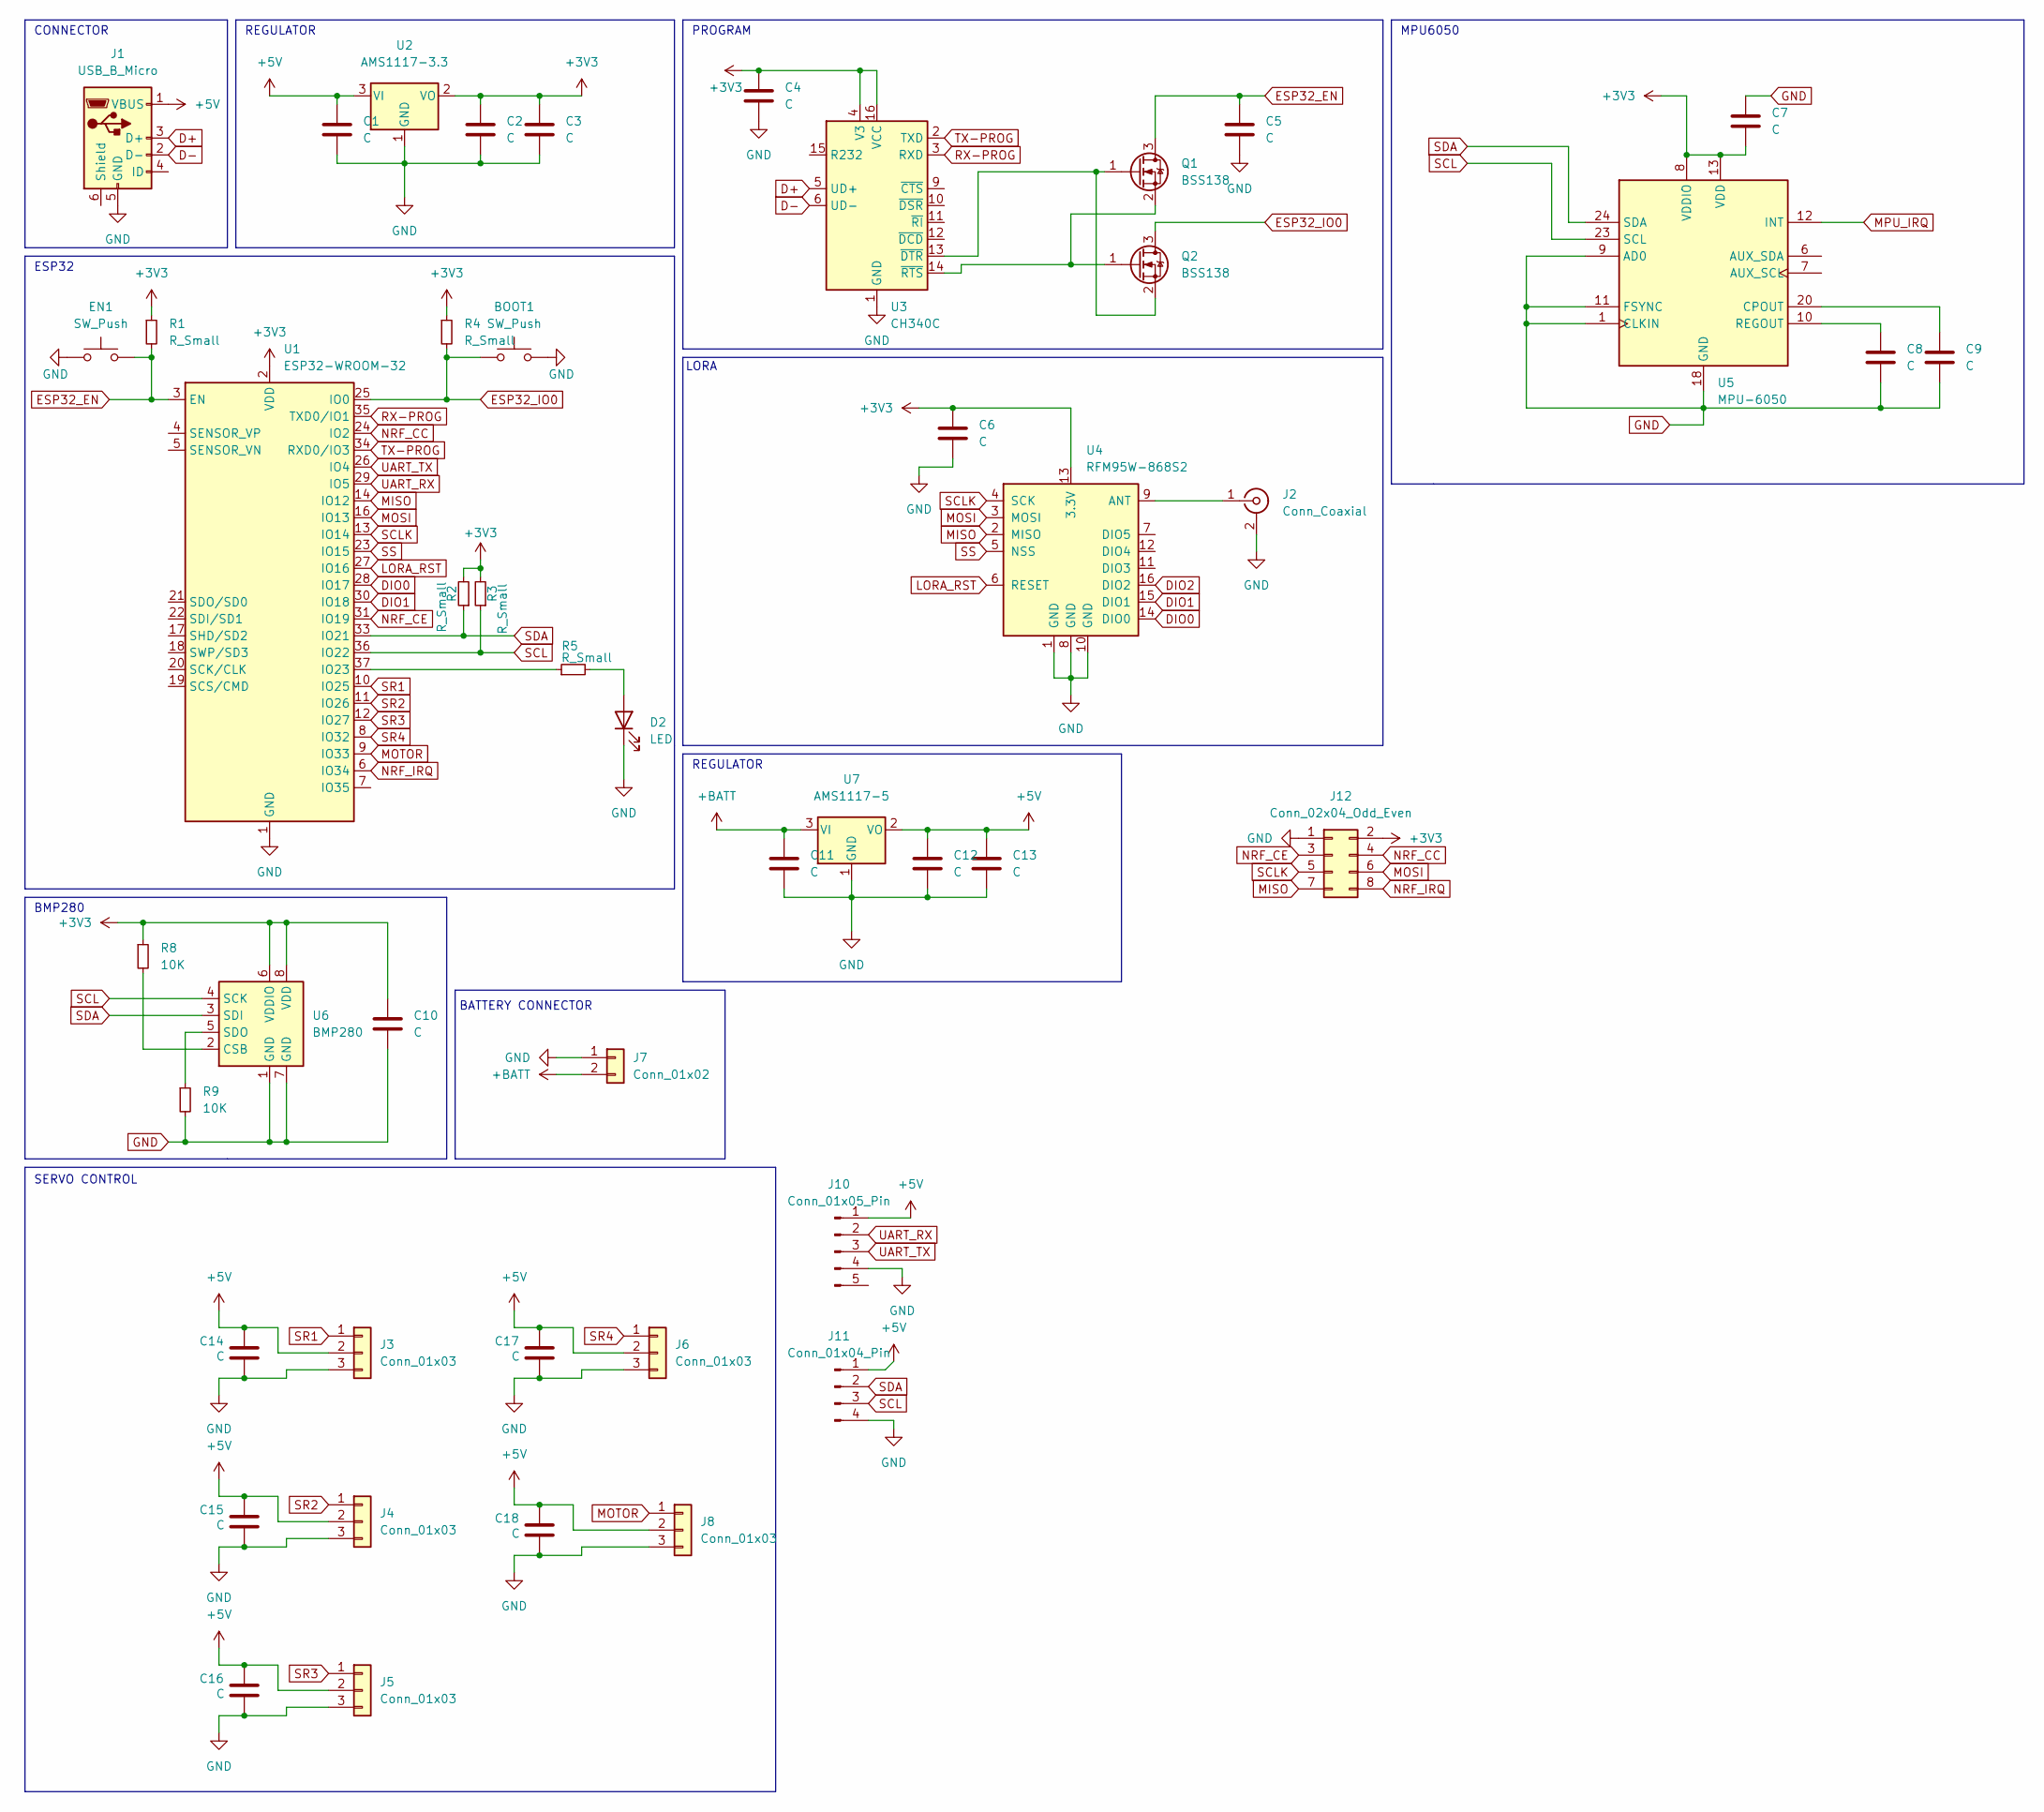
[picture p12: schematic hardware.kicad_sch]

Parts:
BOOT1: SW_Push; SW_SPST_FSMSM
C1, C2, C3, C4, C5, C6, C7, C8, C9, C10, C11, C12, C13, C14, C15, C16, C17, C18: C; C_0603_1608Metric
D2: LED; LED_0603_1608Metric
EN1: SW_Push; SW_SPST_FSMSM
J1: USB_B_Micro; USB_Micro-B_Amphenol_10118194_Horizontal
J2: Conn_Coaxial; SMA_Samtec_SMA-J-P-H-ST-EM1_EdgeMount
J3, J4, J5, J6, J8: Conn_01x03; PinHeader_1x03_P2.54mm_Vertical
J7: Conn_01x02; AMASS_XT30U-F_1x02_P5.0mm_Vertical
J10: Conn_01x05_Pin; PinHeader_1x05_P2.54mm_Vertical
J11: Conn_01x04_Pin; PinHeader_1x04_P2.54mm_Vertical
J12: Conn_02x04_Odd_Even; PinHeader_2x04_P2.54mm_Vertical
Q1, Q2: BSS138; SOT-23
R1, R2, R3, R4, R5: R_Small; R_0603_1608Metric
R8, R9: 10K; R_0603_1608Metric
U1: ESP32-WROOM-32
U2: AMS1117-3.3; SOT-223-3_TabPin2
U3: CH340C; SOIC-16_3.9x9.9mm_P1.27mm
U4: RFM95W-868S2; HOPERF_RFM9XW_SMD
U5: MPU-6050; InvenSense_QFN-24_4x4mm_P0.5mm
U6: BMP280; Bosch_LGA-8_2x2.5mm_P0.65mm_ClockwisePinNumbering
U7: AMS1117-5; SOT-223-3_TabPin2

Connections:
+3V3: C2.1, C3.1, C4.1, C6.1, C7.2, C10.1, J12.2, R1.1, R2.2, R3.2, R4.1, R8.1, U1.2 (VDD), U2.2 (VO), U3.4 (V3), U3.16 (VCC), U4.13 (3.3V), U5.8 (VDDIO), U5.13 (VDD), U6.6 (VDDIO), U6.8 (VDD)
+5V: C1.1, C12.1, C13.1, C14.1, C15.1, C16.1, C17.1, C18.1, J1.1 (VBUS), J3.2, J4.2, J5.2, J6.2, J8.2, J10.1, J11.1, U2.3 (VI), U7.2 (VO)
+BATT: C11.1, J7.2, U7.3 (VI)
D+: J1.3 (D+), U3.5 (UD+)
D-: J1.2 (D-), U3.6 (UD-)
DIO0: U1.28 (IO17), U4.14 (DIO0)
DIO1: U1.30 (IO18), U4.15 (DIO1)
DIO2: U4.16 (DIO2)
ESP32_EN: C5.1, EN1.2, Q1.3 (D), R1.2, U1.3 (EN)
ESP32_IO0: BOOT1.1, Q2.3 (D), R4.2, U1.25 (IO0)
GND: BOOT1.2, C1.2, C2.2, C3.2, C4.2, C5.2, C6.2, C7.1, C8.2, C9.2, C10.2, C11.2, C12.2, C13.2, C14.2, C15.2, C16.2, C17.2, C18.2, D2.1 (K), EN1.1, J1.5 (GND), J2.2 (Ext), J3.3, J4.3, J5.3, J6.3, J7.1, J8.3, J10.4, J11.4, J12.1, R9.2, U1.1 (GND), U1.15 (GND), U1.38 (GND), U1.39 (GND), U2.1 (GND), U3.1 (GND), U4.1 (GND), U4.8 (GND), U4.10 (GND), U5.1 (CLKIN), U5.9 (AD0), U5.11 (FSYNC), U5.18 (GND), U6.1 (GND), U6.7 (GND), U7.1 (GND)
LORA_RST: U1.27 (IO16), U4.6 (RESET)
MISO: J12.7, U1.14 (IO12), U4.2 (MISO)
MOSI: J12.6, U1.16 (IO13), U4.3 (MOSI)
MOTOR: J8.1, U1.9 (IO33)
MPU_IRQ: U5.12 (INT)
NRF_CC: J12.4, U1.24 (IO2)
NRF_CE: J12.3, U1.31 (IO19)
NRF_IRQ: J12.8, U1.6 (IO34)
unnamed: D2.2 (A), R5.2
unnamed: J2.1 (In), U4.9 (ANT)
unnamed: Q1.1 (G), Q2.2 (S), U3.13 (~DTR)
unnamed: Q1.2 (S), Q2.1 (G), U3.14 (~RTS)
unnamed: R5.1, U1.37 (IO23)
unnamed: C9.1, U5.20 (CPOUT)
unnamed: C8.1, U5.10 (REGOUT)
unnamed: R8.2, U6.2 (CSB)
unnamed: R9.1, U6.5 (SDO)
RX-PROG: U1.35 (TXD0/IO1), U3.3 (RXD)
SCL: J11.3, R3.1, U1.36 (IO22), U5.23 (SCL), U6.4 (SCK)
SCLK: J12.5, U1.13 (IO14), U4.4 (SCK)
SDA: J11.2, R2.1, U1.33 (IO21), U5.24 (SDA), U6.3 (SDI)
SR1: J3.1, U1.10 (IO25)
SR2: J4.1, U1.11 (IO26)
SR3: J5.1, U1.12 (IO27)
SR4: J6.1, U1.8 (IO32)
SS: U1.23 (IO15), U4.5 (NSS)
TX-PROG: U1.34 (RXD0/IO3), U3.2 (TXD)
UART_RX: J10.2, U1.29 (IO5)
UART_TX: J10.3, U1.26 (IO4)

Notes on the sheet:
ESP32
BMP280
MPU6050
SERVO CONTROL
REGULATOR
LORA
CONNECTOR
BATTERY CONNECTOR
PROGRAM

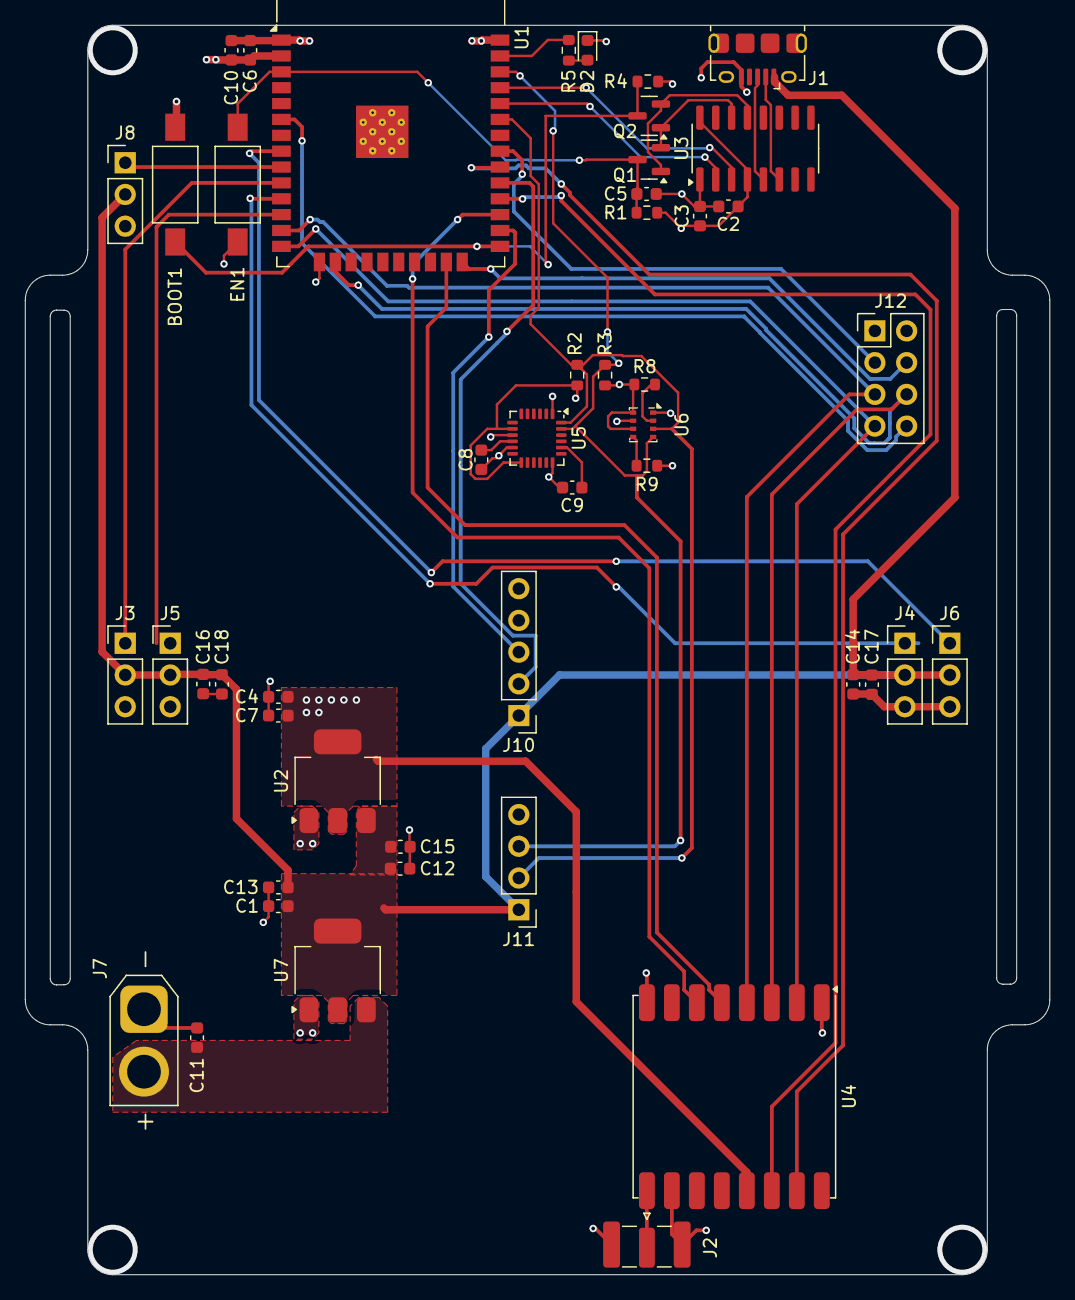
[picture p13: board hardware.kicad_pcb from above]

Board: 4 copper layers, 82.0 x 100.0 mm, 48 parts (0 on the bottom side), 38 nets.

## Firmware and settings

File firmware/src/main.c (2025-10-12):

#include <stdio.h>
#include <string.h>
#include "freertos/FreeRTOS.h"
#include "freertos/task.h"
#include "freertos/semphr.h"
#include "esp_log.h"
#include "esp_system.h"
#include "nvs_flash.h"

#include "config.h"
#include "flight_controller.h"

static const char *TAG = "Main";

static flight_controller_t flight_controller;
static SemaphoreHandle_t fc_mutex;

static void sensor_task(void *pvParameters)
{
    ESP_LOGI(TAG, "Sensor task started");
    TickType_t last_wake_time = xTaskGetTickCount();
    const TickType_t frequency = pdMS_TO_TICKS(1000 / SENSOR_SAMPLE_RATE_HZ);

    while (1) {
        if (xSemaphoreTake(fc_mutex, portMAX_DELAY) == pdTRUE) {
            esp_err_t ret = flight_controller_update_sensors(&flight_controller);
            if (ret != ESP_OK) {
                ESP_LOGE(TAG, "Failed to update sensors");
            }
            xSemaphoreGive(fc_mutex);
        }
        vTaskDelayUntil(&last_wake_time, frequency);
    }
}

static void control_task(void *pvParameters)
{
    ESP_LOGI(TAG, "Control task started");
    TickType_t last_wake_time = xTaskGetTickCount();
    const TickType_t frequency = pdMS_TO_TICKS(1000 / CONTROL_LOOP_RATE_HZ);
    const float dt = 1.0f / CONTROL_LOOP_RATE_HZ;

    while (1) {
        if (xSemaphoreTake(fc_mutex, portMAX_DELAY) == pdTRUE) {
            flight_controller_update_attitude(&flight_controller, dt);
            flight_controller_update_control(&flight_controller, dt);

            // Log every second
            if (flight_controller.loop_count % CONTROL_LOOP_RATE_HZ == 0) {
                ESP_LOGI(TAG, "Attitude: R=%.1f° P=%.1f° Y=%.1f° | Alt=%.2fm | GPS: %.6f,%.6f (%d sats)",
                         flight_controller.attitude.roll,
                         flight_controller.attitude.pitch,
                         flight_controller.attitude.yaw,
                         flight_controller.altitude,
                         flight_controller.gps_data.latitude,
                         flight_controller.gps_data.longitude,
                         flight_controller.gps_data.satellites);

                if (flight_controller.armed) {
                    ESP_LOGI(TAG, "Control outputs: Alt=%.1f Roll=%.1f Pitch=%.1f Yaw=%.1f",
                             flight_controller.altitude_output,
                             flight_controller.roll_output,
                             flight_controller.pitch_output,
                             flight_controller.yaw_output);
                }
            }
            xSemaphoreGive(fc_mutex);
        }
        vTaskDelayUntil(&last_wake_time, frequency);
    }
}

static void gps_task(void *pvParameters)
{
    ESP_LOGI(TAG, "GPS task started");

    while (1) {
        // Read GPS continuously without mutex (GPS has its own buffer)
        gps_read(&flight_controller.gps, 50);

        // Update shared data with mutex
        if (xSemaphoreTake(fc_mutex, pdMS_TO_TICKS(10)) == pdTRUE) {
            gps_get_data(&flight_controller.gps, &flight_controller.gps_data);

            // Log GPS status occasionally
            static int gps_log_counter = 0;
            if (++gps_log_counter >= 50) {  // Every ~5 seconds at 10Hz
                if (flight_controller.gps_data.fix) {
                    ESP_LOGI(TAG, "GPS: %.6f,%.6f Alt:%.1fm Sats:%d Speed:%.1fm/s",
                             flight_controller.gps_data.latitude,
                             flight_controller.gps_data.longitude,
                             flight_controller.gps_data.altitude,
                             flight_controller.gps_data.satellites,
                             flight_controller.gps_data.speed);
                } else {
                    ESP_LOGW(TAG, "GPS: No fix, satellites: %d", flight_controller.gps_data.satellites);
                }
                gps_log_counter = 0;
            }
            xSemaphoreGive(fc_mutex);
        }

        vTaskDelay(pdMS_TO_TICKS(100));  // 10 Hz
    }
}

static void lora_task(void *pvParameters)
{
    ESP_LOGI(TAG, "LoRa task started");
    TickType_t last_wake_time = xTaskGetTickCount();
    const TickType_t frequency = pdMS_TO_TICKS(1000 / LORA_TX_RATE_HZ);

    while (1) {
        if (xSemaphoreTake(fc_mutex, portMAX_DELAY) == pdTRUE) {
            esp_err_t ret = flight_controller_send_telemetry(&flight_controller);
            if (ret != ESP_OK) {
                ESP_LOGW(TAG, "Failed to send telemetry");
            }
            xSemaphoreGive(fc_mutex);
        }
        vTaskDelayUntil(&last_wake_time, frequency);
    }
}

static void wifi_task(void *pvParameters)
{
    ESP_LOGI(TAG, "WiFi task started");
    TickType_t last_wake_time = xTaskGetTickCount();
    const TickType_t frequency = pdMS_TO_TICKS(1000 / WIFI_TX_RATE_HZ);

    while (1) {
        if (xSemaphoreTake(fc_mutex, portMAX_DELAY) == pdTRUE) {
            if (wifi_lr_is_connected(&flight_controller.wifi)) {
                // Send telemetry via WiFi
                uint8_t packet[64];
                int offset = 0;

                memcpy(&packet[offset], &flight_controller.attitude.roll, sizeof(float)); offset += sizeof(float);
                memcpy(&packet[offset], &flight_controller.attitude.pitch, sizeof(float)); offset += sizeof(float);
                memcpy(&packet[offset], &flight_controller.attitude.yaw, sizeof(float)); offset += sizeof(float);
                memcpy(&packet[offset], &flight_controller.altitude, sizeof(float)); offset += sizeof(float);
                memcpy(&packet[offset], &flight_controller.gps_data.latitude, sizeof(float)); offset += sizeof(float);
                memcpy(&packet[offset], &flight_controller.gps_data.longitude, sizeof(float)); offset += sizeof(float);
                memcpy(&packet[offset], &flight_controller.gps_data.satellites, sizeof(uint8_t)); offset += sizeof(uint8_t);
                packet[offset++] = flight_controller.armed ? 1 : 0;

                wifi_lr_send_telemetry(&flight_controller.wifi, packet, offset);

                // Log WiFi status occasionally
                static int wifi_log_counter = 0;
                if (++wifi_log_counter >= 25) {  // Every ~5 seconds at 5Hz
                    int rssi = wifi_lr_get_rssi(&flight_controller.wifi);
                    ESP_LOGI(TAG, "WiFi connected, RSSI: %d dBm", rssi);
                    wifi_log_counter = 0;
                }
            }
            xSemaphoreGive(fc_mutex);
        }
        vTaskDelayUntil(&last_wake_time, frequency);
    }
}

static void command_task(void *pvParameters)
{
    ESP_LOGI(TAG, "Command task started");
    uint8_t rx_buffer[64];

    while (1) {
        int len = rfm95_receive(&flight_controller.lora, rx_buffer, sizeof(rx_buffer), 100);

        if (len > 0) {
            ESP_LOGI(TAG, "Received %d bytes via LoRa", len);

            if (xSemaphoreTake(fc_mutex, portMAX_DELAY) == pdTRUE) {
                if (len >= 1) {
                    switch (rx_buffer[0]) {
                    case 'A':
                        ESP_LOGI(TAG, "Arm command received");
                        flight_controller_arm(&flight_controller);
                        break;

                    case 'D':
                        ESP_LOGI(TAG, "Disarm command received");
                        flight_controller_disarm(&flight_controller);
                        break;

                    case 'S':
                        if (len >= 17) {
                            float altitude, roll, pitch, yaw;
                            memcpy(&altitude, &rx_buffer[1], sizeof(float));
                            memcpy(&roll, &rx_buffer[5], sizeof(float));
                            memcpy(&pitch, &rx_buffer[9], sizeof(float));
                            memcpy(&yaw, &rx_buffer[13], sizeof(float));

                            ESP_LOGI(TAG, "Setpoint command: Alt=%.1f R=%.1f P=%.1f Y=%.1f",
                                     altitude, roll, pitch, yaw);

                            flight_controller_set_altitude(&flight_controller, altitude);
                            flight_controller_set_attitude(&flight_controller, roll, pitch, yaw);
                        }
                        break;

                    case 'W':  // WiFi connect command
                        if (len >= 2) {
                            char ssid[32] = {0};
                            char password[64] = {0};
                            int ssid_len = rx_buffer[1];
                            if (ssid_len > 0 && ssid_len < 32 && len >= 2 + ssid_len) {
                                memcpy(ssid, &rx_buffer[2], ssid_len);
                                ssid[ssid_len] = '\0';

                                if (len > 2 + ssid_len) {
                                    int pass_len = len - 2 - ssid_len;
                                    if (pass_len < 64) {
                                        memcpy(password, &rx_buffer[2 + ssid_len], pass_len);
                                        password[pass_len] = '\0';
                                    }
                                }

                                ESP_LOGI(TAG, "WiFi connect command: %s", ssid);
                                wifi_lr_connect(&flight_controller.wifi, ssid, password);
                            }
                        }
                        break;

                    case 'P':
                        ESP_LOGI(TAG, "PID update command (not implemented)");
                        break;

                    default:
                        ESP_LOGW(TAG, "Unknown command: 0x%02X", rx_buffer[0]);
                        break;
                    }
                }
                xSemaphoreGive(fc_mutex);
            }
        }
        vTaskDelay(pdMS_TO_TICKS(100));
    }
}

void app_main(void)
{
    ESP_LOGI(TAG, "========================================");
    ESP_LOGI(TAG, "Falcon-Edge Flight Controller");
    ESP_LOGI(TAG, "FreeRTOS-based ESP32 Firmware");
    ESP_LOGI(TAG, "========================================");

    esp_err_t ret = nvs_flash_init();
    if (ret == ESP_ERR_NVS_NO_FREE_PAGES || ret == ESP_ERR_NVS_NEW_VERSION_FOUND) {
        ESP_ERROR_CHECK(nvs_flash_erase());
        ret = nvs_flash_init();
    }
    ESP_ERROR_CHECK(ret);

    fc_mutex = xSemaphoreCreateMutex();
    if (fc_mutex == NULL) {
        ESP_LOGE(TAG, "Failed to create mutex");
        return;
    }

    ESP_LOGI(TAG, "Initializing flight controller...");
    ret = flight_controller_init(&flight_controller);
    if (ret != ESP_OK) {
        ESP_LOGE(TAG, "Failed to initialize flight controller: %s", esp_err_to_name(ret));
        return;
    }

    flight_controller_set_altitude(&flight_controller, flight_controller.altitude);
    flight_controller_set_attitude(&flight_controller, 0.0f, 0.0f, flight_controller.attitude.yaw);

    ESP_LOGI(TAG, "Creating FreeRTOS tasks...");

    xTaskCreate(sensor_task, "sensor_task", SENSOR_TASK_STACK_SIZE, NULL,
                SENSOR_TASK_PRIORITY, NULL);

    xTaskCreate(control_task, "control_task", CONTROL_TASK_STACK_SIZE, NULL,
                CONTROL_TASK_PRIORITY, NULL);

    xTaskCreate(gps_task, "gps_task", GPS_TASK_STACK_SIZE, NULL,
                GPS_TASK_PRIORITY, NULL);

    xTaskCreate(lora_task, "lora_task", LORA_TASK_STACK_SIZE, NULL,
                LORA_TASK_PRIORITY, NULL);

    xTaskCreate(command_task, "command_task", LORA_TASK_STACK_SIZE, NULL,
                LORA_TASK_PRIORITY, NULL);

#if WIFI_ENABLED
    xTaskCreate(wifi_task, "wifi_task", WIFI_TASK_STACK_SIZE, NULL,
                WIFI_TASK_PRIORITY, NULL);
#endif

    ESP_LOGI(TAG, "System initialized successfully!");
    ESP_LOGI(TAG, "Waiting for commands...");
    ESP_LOGI(TAG, "Send 'A' via LoRa to arm the system");

    while (1) {
        vTaskDelay(pdMS_TO_TICKS(10000));
    }
}

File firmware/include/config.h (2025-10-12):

#ifndef CONFIG_H
#define CONFIG_H

// I2C Configuration
#define I2C_MASTER_SCL_IO 22 // GPIO22 for I2C clock
#define I2C_MASTER_SDA_IO 21 // GPIO21 for I2C data
#define I2C_MASTER_NUM I2C_NUM_0
#define I2C_MASTER_FREQ_HZ 400000 // 400kHz
#define I2C_MASTER_TX_BUF_DISABLE 0
#define I2C_MASTER_RX_BUF_DISABLE 0
#define I2C_MASTER_TIMEOUT_MS 1000

// SPI Configuration for RFM95 LoRa
#define SPI_MISO_PIN 12
#define SPI_MOSI_PIN 13
#define SPI_SCK_PIN 14
#define SPI_SS_PIN 15
#define LORA_RST_PIN 16
#define LORA_DIO0_PIN 17
#define LORA_DIO1_PIN 18

// UART Configuration for GPS
#define GPS_UART_NUM UART_NUM_1
#define GPS_TX_PIN 5
#define GPS_RX_PIN 4
#define GPS_BAUD_RATE 9600
#define GPS_RX_BUF_SIZE 1024

// Sensor I2C Addresses
#define BMP280_I2C_ADDR 0x77 // or 0x77
#define HMC5883L_I2C_ADDR 0x1E
#define MPU6050_I2C_ADDR 0x68 // or 0x69

// PID Configuration - Altitude
#define ALT_PID_KP 2.0f
#define ALT_PID_KI 0.5f
#define ALT_PID_KD 1.0f
#define ALT_PID_MAX_OUTPUT 100.0f
#define ALT_PID_MIN_OUTPUT -100.0f
#define ALT_PID_MAX_INTEGRAL 50.0f

// PID Configuration - Roll
#define ROLL_PID_KP 1.5f
#define ROLL_PID_KI 0.3f
#define ROLL_PID_KD 0.8f
#define ROLL_PID_MAX_OUTPUT 100.0f
#define ROLL_PID_MIN_OUTPUT -100.0f
#define ROLL_PID_MAX_INTEGRAL 50.0f

// PID Configuration - Pitch
#define PITCH_PID_KP 1.5f
#define PITCH_PID_KI 0.3f
#define PITCH_PID_KD 0.8f
#define PITCH_PID_MAX_OUTPUT 100.0f
#define PITCH_PID_MIN_OUTPUT -100.0f
#define PITCH_PID_MAX_INTEGRAL 50.0f

// PID Configuration - Yaw
#define YAW_PID_KP 2.0f
#define YAW_PID_KI 0.1f
#define YAW_PID_KD 1.2f
#define YAW_PID_MAX_OUTPUT 100.0f
#define YAW_PID_MIN_OUTPUT -100.0f
#define YAW_PID_MAX_INTEGRAL 30.0f

// WiFi Long Range Configuration
#define WIFI_ENABLED true                // Set to false to disable WiFi
#define WIFI_DEFAULT_SSID "DroneGCS"     // Change to your network
#define WIFI_DEFAULT_PASSWORD "drone123" // Change to your password

// FreeRTOS Task Priorities
#define SENSOR_TASK_PRIORITY 5
#define CONTROL_TASK_PRIORITY 6
#define GPS_TASK_PRIORITY 3
#define LORA_TASK_PRIORITY 2
#define WIFI_TASK_PRIORITY 2

// FreeRTOS Task Stack Sizes
#define SENSOR_TASK_STACK_SIZE 4096
#define CONTROL_TASK_STACK_SIZE 4096
#define GPS_TASK_STACK_SIZE 3072
#define LORA_TASK_STACK_SIZE 3072
#define WIFI_TASK_STACK_SIZE 4096

// Control Loop Rates (Hz)
#define SENSOR_SAMPLE_RATE_HZ 100
#define CONTROL_LOOP_RATE_HZ 100
#define GPS_READ_RATE_HZ 10
#define LORA_TX_RATE_HZ 1
#define WIFI_TX_RATE_HZ 5

// Complementary Filter
#define ALPHA_GYRO 0.98f
#define ALPHA_ACCEL 0.02f

#endif // CONFIG_H

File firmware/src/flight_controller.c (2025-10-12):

#include "flight_controller.h"
#include "config.h"
#include "esp_log.h"
#include <math.h>
#include <string.h>

static const char *TAG = "FlightController";

esp_err_t flight_controller_init(flight_controller_t *fc)
{
    memset(fc, 0, sizeof(flight_controller_t));

    ESP_LOGI(TAG, "Initializing I2C...");
    i2c_config_t i2c_conf = {
        .mode = I2C_MODE_MASTER,
        .sda_io_num = I2C_MASTER_SDA_IO,
        .scl_io_num = I2C_MASTER_SCL_IO,
        .sda_pullup_en = GPIO_PULLUP_ENABLE,
        .scl_pullup_en = GPIO_PULLUP_ENABLE,
        .master.clk_speed = I2C_MASTER_FREQ_HZ,
    };

    esp_err_t ret = i2c_param_config(I2C_MASTER_NUM, &i2c_conf);
    if (ret != ESP_OK) {
        ESP_LOGE(TAG, "Failed to configure I2C");
        return ret;
    }

    ret = i2c_driver_install(I2C_MASTER_NUM, I2C_MODE_MASTER,
                             I2C_MASTER_RX_BUF_DISABLE,
                             I2C_MASTER_TX_BUF_DISABLE, 0);
    if (ret != ESP_OK) {
        ESP_LOGE(TAG, "Failed to install I2C driver");
        return ret;
    }

    ESP_LOGI(TAG, "Initializing MPU6050...");
    ret = mpu6050_init(&fc->mpu6050, I2C_MASTER_NUM, MPU6050_I2C_ADDR);
    if (ret != ESP_OK) {
        ESP_LOGE(TAG, "Failed to initialize MPU6050");
        return ret;
    }

    ESP_LOGI(TAG, "Initializing HMC5883L...");
    ret = hmc5883l_init(&fc->hmc5883l, I2C_MASTER_NUM, HMC5883L_I2C_ADDR);
    if (ret != ESP_OK) {
        ESP_LOGE(TAG, "Failed to initialize HMC5883L");
        return ret;
    }

    ESP_LOGI(TAG, "Initializing BMP280...");
    ret = bmp280_init(&fc->bmp280, I2C_MASTER_NUM, BMP280_I2C_ADDR);
    if (ret != ESP_OK) {
        ESP_LOGW(TAG, "BMP280 not found (altitude control disabled)");
        fc->has_bmp280 = false;
    } else {
        fc->has_bmp280 = true;
        ESP_LOGI(TAG, "BMP280 initialized successfully");
    }

    ESP_LOGI(TAG, "Initializing GPS...");
    ret = gps_init(&fc->gps, GPS_UART_NUM, GPS_TX_PIN, GPS_RX_PIN);
    if (ret != ESP_OK) {
        ESP_LOGE(TAG, "Failed to initialize GPS");
        return ret;
    }

    ESP_LOGI(TAG, "Initializing LoRa...");
    ret = rfm95_init(&fc->lora, SPI2_HOST, RFM95_FREQ_915MHZ);
    if (ret != ESP_OK) {
        ESP_LOGE(TAG, "Failed to initialize LoRa");
        return ret;
    }

#if WIFI_ENABLED
    ESP_LOGI(TAG, "Initializing WiFi Long Range...");
    ret = wifi_lr_init(&fc->wifi);
    if (ret != ESP_OK) {
        ESP_LOGW(TAG, "WiFi init failed, continuing without WiFi");
    } else {
        // Auto-connect if default credentials are set
        if (strlen(WIFI_DEFAULT_SSID) > 0) {
            wifi_lr_connect(&fc->wifi, WIFI_DEFAULT_SSID, WIFI_DEFAULT_PASSWORD);
        }
    }
#endif

    ESP_LOGI(TAG, "Initializing motor control...");
    ret = motor_control_init(&fc->motor);
    if (ret != ESP_OK) {
        ESP_LOGE(TAG, "Failed to initialize motor control");
        return ret;
    }

    ESP_LOGI(TAG, "Initializing PID controllers...");
    pid_init(&fc->altitude_pid, ALT_PID_KP, ALT_PID_KI, ALT_PID_KD,
             ALT_PID_MAX_OUTPUT, ALT_PID_MIN_OUTPUT, ALT_PID_MAX_INTEGRAL);

    pid_init(&fc->roll_pid, ROLL_PID_KP, ROLL_PID_KI, ROLL_PID_KD,
             ROLL_PID_MAX_OUTPUT, ROLL_PID_MIN_OUTPUT, ROLL_PID_MAX_INTEGRAL);

    pid_init(&fc->pitch_pid, PITCH_PID_KP, PITCH_PID_KI, PITCH_PID_KD,
             PITCH_PID_MAX_OUTPUT, PITCH_PID_MIN_OUTPUT, PITCH_PID_MAX_INTEGRAL);

    pid_init(&fc->yaw_pid, YAW_PID_KP, YAW_PID_KI, YAW_PID_KD,
             YAW_PID_MAX_OUTPUT, YAW_PID_MIN_OUTPUT, YAW_PID_MAX_INTEGRAL);

    ESP_LOGI(TAG, "Calibrating IMU...");
    ret = mpu6050_calibrate(&fc->mpu6050);
    if (ret != ESP_OK) {
        ESP_LOGE(TAG, "Failed to calibrate MPU6050");
        return ret;
    }

    fc->calibrated = true;
    fc->armed = false;

    ESP_LOGI(TAG, "Flight controller initialized successfully");
    return ESP_OK;
}

esp_err_t flight_controller_update_sensors(flight_controller_t *fc)
{
    esp_err_t ret = mpu6050_read_data(&fc->mpu6050, &fc->imu_data);
    if (ret != ESP_OK) {
        ESP_LOGE(TAG, "Failed to read MPU6050");
        return ret;
    }

    ret = hmc5883l_read_data(&fc->hmc5883l, &fc->mag_data);
    if (ret != ESP_OK) {
        ESP_LOGE(TAG, "Failed to read HMC5883L");
        return ret;
    }

    if (fc->has_bmp280) {
        ret = bmp280_read_data(&fc->bmp280, &fc->temperature, &fc->pressure, &fc->altitude);
        if (ret != ESP_OK) {
            ESP_LOGW(TAG, "Failed to read BMP280");
        }
    }

    return ESP_OK;
}

void flight_controller_update_attitude(flight_controller_t *fc, float dt)
{
    // Get roll/pitch from accelerometer
    float accel_roll = atan2f(fc->imu_data.accel.y, fc->imu_data.accel.z) * 180.0f / M_PI;
    float accel_pitch = atan2f(-fc->imu_data.accel.x,
                               sqrtf(fc->imu_data.accel.y * fc->imu_data.accel.y +
                                     fc->imu_data.accel.z * fc->imu_data.accel.z)) * 180.0f / M_PI;

    // Integrate gyro
    fc->attitude.roll += fc->imu_data.gyro.x * dt;
    fc->attitude.pitch += fc->imu_data.gyro.y * dt;
    fc->attitude.yaw += fc->imu_data.gyro.z * dt;

    // Complementary filter to fuse accel and gyro
    fc->attitude.roll = ALPHA_GYRO * fc->attitude.roll + ALPHA_ACCEL * accel_roll;
    fc->attitude.pitch = ALPHA_GYRO * fc->attitude.pitch + ALPHA_ACCEL * accel_pitch;

    // Tilt-compensated compass heading
    float mag_x = fc->mag_data.x * cosf(fc->attitude.pitch * M_PI / 180.0f) +
                  fc->mag_data.z * sinf(fc->attitude.pitch * M_PI / 180.0f);

    float mag_y = fc->mag_data.x * sinf(fc->attitude.roll * M_PI / 180.0f) *
                      sinf(fc->attitude.pitch * M_PI / 180.0f) +
                  fc->mag_data.y * cosf(fc->attitude.roll * M_PI / 180.0f) -
                  fc->mag_data.z * sinf(fc->attitude.roll * M_PI / 180.0f) *
                      cosf(fc->attitude.pitch * M_PI / 180.0f);

    float mag_heading = atan2f(mag_y, mag_x) * 180.0f / M_PI;
    if (mag_heading < 0) {
        mag_heading += 360.0f;
    }

    // Slowly correct yaw drift with compass
    float yaw_diff = mag_heading - fc->attitude.yaw;
    if (yaw_diff > 180.0f) yaw_diff -= 360.0f;
    if (yaw_diff < -180.0f) yaw_diff += 360.0f;
    fc->attitude.yaw += yaw_diff * 0.01f;

    // Keep yaw in 0-360 range
    if (fc->attitude.yaw < 0) fc->attitude.yaw += 360.0f;
    if (fc->attitude.yaw >= 360.0f) fc->attitude.yaw -= 360.0f;
}
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

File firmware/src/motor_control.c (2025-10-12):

#include "motor_control.h"
#include "driver/ledc.h"
#include "esp_log.h"
#include "freertos/FreeRTOS.h"
#include "freertos/task.h"
#include <math.h>

static const char *TAG = "MotorControl";

#define LEDC_TIMER              LEDC_TIMER_0
#define LEDC_MODE               LEDC_LOW_SPEED_MODE
#define LEDC_DUTY_RES           LEDC_TIMER_13_BIT
#define LEDC_FREQUENCY          50

static uint32_t angle_to_pulse_us(float angle)
{
    // Map -45 to +45 degrees to 1000-2000us
    if (angle < -45.0f) angle = -45.0f;
    if (angle > 45.0f) angle = 45.0f;

    float pulse = SERVO_CENTER_PULSE_US + (angle / 45.0f) * 500.0f;
    return (uint32_t)pulse;
}

static uint32_t throttle_to_pulse_us(float throttle)
{
    // Map 0-100% to ESC_MIN to ESC_MAX
    if (throttle < 0.0f) throttle = 0.0f;
    if (throttle > 100.0f) throttle = 100.0f;

    uint32_t pulse = ESC_MIN_PULSE_US + (uint32_t)((throttle / 100.0f) * (ESC_MAX_PULSE_US - ESC_MIN_PULSE_US));
    return pulse;
}

static uint32_t pulse_us_to_duty(uint32_t pulse_us)
{
    // Calculate duty cycle for LEDC
    // duty = (pulse_us / period_us) * (2^duty_resolution)
    uint32_t period_us = 1000000 / LEDC_FREQUENCY;
    uint32_t max_duty = (1 << LEDC_DUTY_RES);
    uint32_t duty = (pulse_us * max_duty) / period_us;
    return duty;
}

esp_err_t motor_control_init(motor_control_t *motor)
{
    motor->initialized = false;
    motor->servo_left_angle = 0.0f;
    motor->servo_right_angle = 0.0f;
    motor->throttle = 0.0f;

    // Configure LEDC timer
    ledc_timer_config_t ledc_timer = {
        .speed_mode       = LEDC_MODE,
        .timer_num        = LEDC_TIMER,
        .duty_resolution  = LEDC_DUTY_RES,
        .freq_hz          = LEDC_FREQUENCY,
        .clk_cfg          = LEDC_AUTO_CLK
    };
    esp_err_t ret = ledc_timer_config(&ledc_timer);
    if (ret != ESP_OK) {
        ESP_LOGE(TAG, "Failed to configure LEDC timer");
        return ret;
    }

    // Configure left servo channel
    ledc_channel_config_t left_servo = {
        .speed_mode     = LEDC_MODE,
        .channel        = LEDC_CHANNEL_0,
        .timer_sel      = LEDC_TIMER,
        .intr_type      = LEDC_INTR_DISABLE,
        .gpio_num       = SERVO_LEFT_GPIO,
        .duty           = pulse_us_to_duty(SERVO_CENTER_PULSE_US),
        .hpoint         = 0
    };
    ret = ledc_channel_config(&left_servo);
    if (ret != ESP_OK) {
        ESP_LOGE(TAG, "Failed to configure left servo");
        return ret;
    }
    motor->servo_left_channel = LEDC_CHANNEL_0;

    // Configure right servo channel
    ledc_channel_config_t right_servo = {
        .speed_mode     = LEDC_MODE,
        .channel        = LEDC_CHANNEL_1,
        .timer_sel      = LEDC_TIMER,
        .intr_type      = LEDC_INTR_DISABLE,
        .gpio_num       = SERVO_RIGHT_GPIO,
        .duty           = pulse_us_to_duty(SERVO_CENTER_PULSE_US),
        .hpoint         = 0
    };
    ret = ledc_channel_config(&right_servo);
    if (ret != ESP_OK) {
        ESP_LOGE(TAG, "Failed to configure right servo");
        return ret;
    }
    motor->servo_right_channel = LEDC_CHANNEL_1;

    // Configure ESC channel (start at min throttle)
    ledc_channel_config_t esc = {
        .speed_mode     = LEDC_MODE,
        .channel        = LEDC_CHANNEL_2,
        .timer_sel      = LEDC_TIMER,
        .intr_type      = LEDC_INTR_DISABLE,
        .gpio_num       = ESC_GPIO,
        .duty           = pulse_us_to_duty(ESC_MIN_PULSE_US),
        .hpoint         = 0
    };
    ret = ledc_channel_config(&esc);
    if (ret != ESP_OK) {
        ESP_LOGE(TAG, "Failed to configure ESC");
        return ret;
    }
    motor->esc_channel = LEDC_CHANNEL_2;

    motor->initialized = true;
    ESP_LOGI(TAG, "Motor control initialized - Left:%d Right:%d ESC:%d",
             SERVO_LEFT_GPIO, SERVO_RIGHT_GPIO, ESC_GPIO);

    return ESP_OK;
}

esp_err_t motor_set_servo_left(motor_control_t *motor, float angle)
{
    if (!motor->initialized) {
        return ESP_ERR_INVALID_STATE;
    }

    motor->servo_left_angle = angle;
    uint32_t pulse = angle_to_pulse_us(angle);
    uint32_t duty = pulse_us_to_duty(pulse);

    return ledc_set_duty(LEDC_MODE, motor->servo_left_channel, duty) ||
           ledc_update_duty(LEDC_MODE, motor->servo_left_channel);
}

esp_err_t motor_set_servo_right(motor_control_t *motor, float angle)
{
    if (!motor->initialized) {
        return ESP_ERR_INVALID_STATE;
    }

    motor->servo_right_angle = angle;
    uint32_t pulse = angle_to_pulse_us(angle);
    uint32_t duty = pulse_us_to_duty(pulse);

    return ledc_set_duty(LEDC_MODE, motor->servo_right_channel, duty) ||
           ledc_update_duty(LEDC_MODE, motor->servo_right_channel);
}

esp_err_t motor_set_throttle(motor_control_t *motor, float throttle)
{
    if (!motor->initialized) {
        return ESP_ERR_INVALID_STATE;
    }

    motor->throttle = throttle;
    uint32_t pulse = throttle_to_pulse_us(throttle);
    uint32_t duty = pulse_us_to_duty(pulse);

    return ledc_set_duty(LEDC_MODE, motor->esc_channel, duty) ||
           ledc_update_duty(LEDC_MODE, motor->esc_channel);
}

esp_err_t motor_set_all(motor_control_t *motor, float left_angle, float right_angle, float throttle)
{
    esp_err_t ret;

    ret = motor_set_servo_left(motor, left_angle);
    if (ret != ESP_OK) return ret;

    ret = motor_set_servo_right(motor, right_angle);
    if (ret != ESP_OK) return ret;

    ret = motor_set_throttle(motor, throttle);
    return ret;
}

esp_err_t motor_arm_esc(motor_control_t *motor)
{
    if (!motor->initialized) {
        return ESP_ERR_INVALID_STATE;
    }

    ESP_LOGI(TAG, "Arming ESC sequence...");

    // ESC arming sequence: min throttle for 2 seconds
    uint32_t duty = pulse_us_to_duty(ESC_MIN_PULSE_US);
    ledc_set_duty(LEDC_MODE, motor->esc_channel, duty);
    ledc_update_duty(LEDC_MODE, motor->esc_channel);

    vTaskDelay(pdMS_TO_TICKS(2000));

    ESP_LOGI(TAG, "ESC armed");
    return ESP_OK;
}

esp_err_t motor_disarm(motor_control_t *motor)
{
    if (!motor->initialized) {
        return ESP_ERR_INVALID_STATE;
    }

    ESP_LOGI(TAG, "Disarming motors");

    // Center servos
    motor_set_servo_left(motor, 0.0f);
    motor_set_servo_right(motor, 0.0f);

    // Min throttle
    motor_set_throttle(motor, 0.0f);

    return ESP_OK;
}

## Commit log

2025-08-28 first commit pcb
    [hardware.kicad_pcb, hardware.kicad_sch]
2025-08-28 update wiring
    [hardware.kicad_pcb]
2025-08-28 add battery fix
    [hardware.kicad_pcb]
2025-09-21 add schematic position system
    [position_hardware.kicad_pcb, position_hardware.kicad_sch]
2025-09-21 position system hardware pcb
    [position_hardware.kicad_pcb]
2025-10-03 minimal schematic components
    [camera-stabilization_hardware.kicad_pcb, camera-stabilization_hardware.kicad_sch]
2025-10-03 added pcb wiring camera stabilization
    [camera-stabilization_hardware.kicad_pcb, camera-stabilization_hardware.kicad_sch]
2025-10-12 add firmware
    [camera-stabilization_hardware.kicad_sch, position_hardware.kicad_sch]
